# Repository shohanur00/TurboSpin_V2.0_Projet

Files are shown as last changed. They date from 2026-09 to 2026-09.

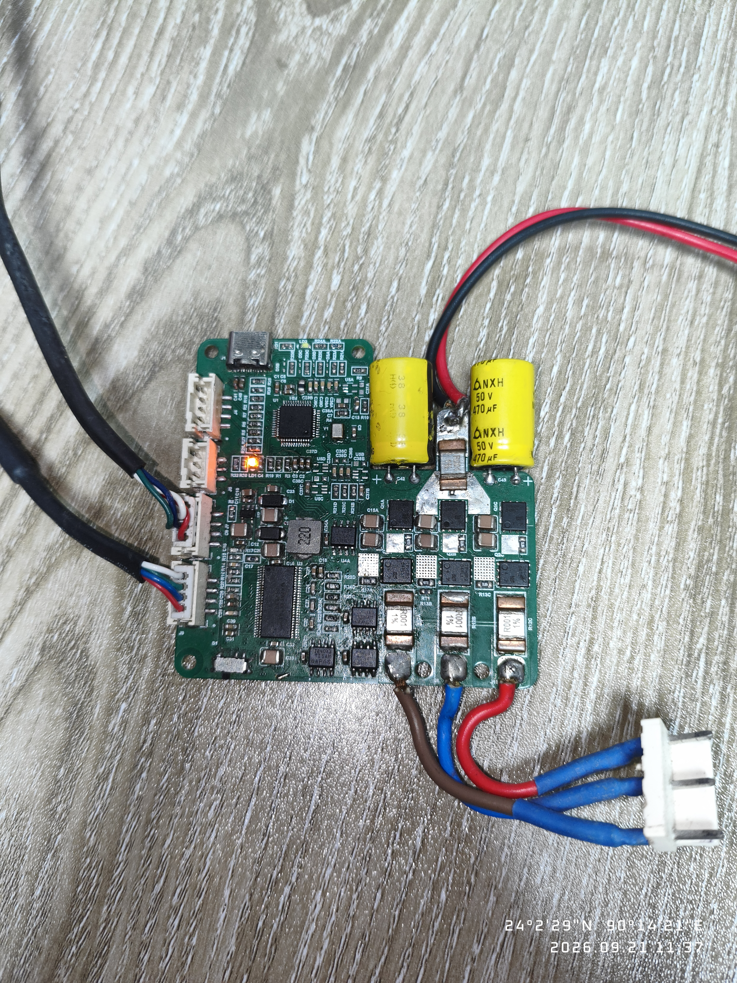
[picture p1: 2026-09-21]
Image/Hardware.jpeg

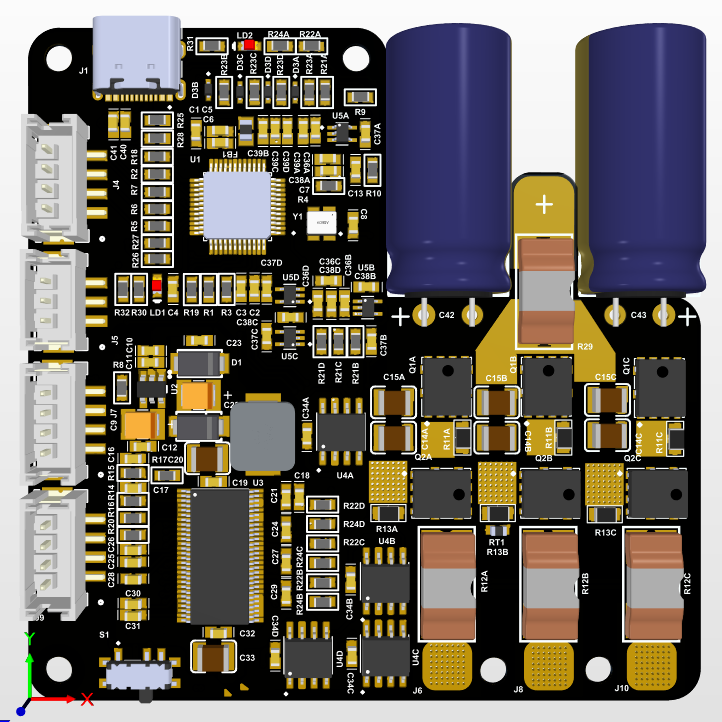
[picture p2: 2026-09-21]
Image/TurboSpin_V2_Front.png

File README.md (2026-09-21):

<div align="center">

# ⚡ TurboSpin V2

### 40A-class Sensorless BLDC / FOC ESC — Hardware Platform

*Design the hardware. Understand the current. Control the motor.*

<br>













</div>

---

**TurboSpin V2** is a custom **40A-class sensorless BLDC ESC** built around the **STM32G431CBT6** microcontroller and the **DRV8301** three-phase gate driver.

It is a compact, learning-oriented hardware platform with a dedicated power stage, current sensing and protection circuitry, and an MCU architecture ready for **six-step sensorless control and sensorless FOC** firmware.

> **Project status:** hardware design complete · firmware development in progress

## 📑 Contents

[Demo](#-demo) · [Key features](#-key-features) · [Architecture](#-hardware-architecture) · [Components](#-main-components) · [Subsystems](#-subsystems) · [Thermal](#-thermal-design) · [PCB philosophy](#-pcb-design-philosophy) · [Repository](#-repository-structure) · [Roadmap](#-roadmap) · [Safety](#-safety) · [Author](#-author)

---

## 🎬 Demo

<!-- Upload the clip to the repo (or drag it into a GitHub issue/README edit box) and update the path. -->
https://github.com/shohanur00/TurboSpin_V2.0_Projet/blob/main/Test/TurboSpin_V2.mp4

---

## ✨ Key Features

| | |
|---|---|
| ⚡ **Power** | 40A-class 3-phase MOSFET power stage |
| 🧠 **Control** | STM32G431CBT6 with advanced motor-control timers, fast ADCs and DMA |
| 🔌 **Gate drive** | DRV8301 with fault reporting |
| 📏 **Current sensing** | Low-side shunt + INA240A1 (20 V/V) |
| 🛡️ **Protection** | Hardware over-current architecture, gate-driver fault handling |
| 🔄 **Sensorless** | External comparator for back-EMF zero-cross detection |
| 📡 **Interfaces** | DShot and telemetry (planned), USB (planned), SWD debug |
| 🔥 **Layout** | High-current PCB with thermal considerations |

---

## 🏗️ Hardware Architecture

```text
                 ┌─────────────────────┐
                 │    Control Input    │
                 │  DShot / Future USB │
                 └──────────┬──────────┘
                            ▼
┌───────────────────────────────────────────────────────┐
│                     STM32G431CBT6                     │
│  PWM Generation │ ADC │ Timers │ DMA │ Protection     │
│               Future FOC / Control FW                 │
└─────────────┬─────────────────────────────▲───────────┘
              │ PWM (3 × complementary)     │ Current feedback
              ▼                             │
     ┌─────────────────┐            ┌───────┴──────────┐
     │     DRV8301     │            │ Shunt + INA240A1 │
     │  3-Phase Gate   │            └───────▲──────────┘
     │     Driver      │                    │
     └────────┬────────┘                    │
              ▼                             │
     ┌─────────────────┐                    │
     │  MOSFET Power   │────────────────────┘
     │  Stage (3 × ½B) │
     └────────┬────────┘
              │
        U ────┼──── V ──── W
              ▼
        BLDC / PMSM Motor
```

---

## 🔌 Main Components

| Function | Component |
| --- | --- |
| MCU | STM32G431CBT6 |
| Gate driver | DRV8301DCAR |
| Current amplifier | INA240A1 |
| Current shunt | 10 mΩ class <!-- TODO: verify final shunt value against BOM --> |
| Power MOSFET | TPH1R204PL1 |
| Motor phases | U / V / W |
| Control interface | DShot / future interfaces |
| Debug | SWD |
| USB | USB 2.0 |
| Sensorless feedback | External comparator |
| Input voltage | _TBD_ |

---

## 🧩 Subsystems

### 🧠 Microcontroller — STM32G431CBT6

Chosen for its motor-control peripherals: Cortex-M4 core, advanced PWM timers, high-speed ADCs, analog peripherals, DMA, multiple communication interfaces and SWD debugging.

```text
PWM Generation ──► 3-phase inverter
ADC ─────────────► Phase / bus current · DC bus voltage · Temperature
Comparator ──────► Sensorless feedback
                   └──► Motor control algorithm
```

### ⚡ Power Stage

A 3-phase MOSFET inverter with one high-side and one low-side switch per phase.

```text
                DC BUS
                  │
        ┌─────────┼─────────┐
       HS-U      HS-V      HS-W
        ├── U     ├── V     ├── W
       LS-U      LS-V      LS-W
        └─────────┼─────────┘
                 GND
```

Layout considerations: high-current paths, switching loops, gate-drive return paths, power/logic ground separation, current-sense routing, thermal dissipation, switching-node noise and low-inductance connections.

### 🔋 Gate Driver — DRV8301

Handles high-side / low-side gate drive, gate-drive supply management, current-sense amplifier interface, protection and fault reporting. The STM32 generates complementary PWM with firmware-controlled dead time to prevent shoot-through.

### 📏 Current Sensing

```text
Motor current ─► Low-side shunt ─► INA240A1 (20 V/V) ─► STM32 ADC
```

Used for current monitoring, limiting, protection, future FOC current-loop control and diagnostics. Kelvin-style routing around the shunt and amplifier keeps measurement error and switching noise low.

### 🛡️ Protection

Hardware and firmware layers, designed so critical faults can disable the power stage independently of normal control where practical:

* Over-current protection
* Gate-driver fault detection
* DC bus over-voltage / under-voltage monitoring
* MOSFET / board temperature monitoring
* PWM shutdown on fault

### 🔄 Sensorless Feedback

```text
Motor back-EMF ─► Comparator ─► STM32G431 ─► Zero-cross / rotor position
```

Supports six-step sensorless commutation, back-EMF zero-cross detection, sensorless startup and future sensorless FOC research.

### 🔌 USB and Communication

Planned: configuration, debugging, firmware update, parameter monitoring and PC tools over USB; DShot and telemetry for flight-controller use; SWD for debug. The USB pair is routed short with series termination. **Firmware support is not implemented yet**, and protocol details may evolve.

---

## 🌡️ Thermal Design

Key considerations: MOSFET dissipation, copper area around power devices, thermal vias, high-current routing, gate-driver thermals, shunt dissipation and PCB temperature monitoring.

> [!NOTE]
> **40A is a design-class target, not a guaranteed continuous rating.** Real capability depends on PCB construction, copper thickness, cooling, switching conditions, motor and environment.

---

## 🎯 PCB Design Philosophy

| Area | Approach |
| --- | --- |
| **Power path** | Short, wide, low-impedance, low-inductance |
| **Gate drive** | Compact loops to reduce ringing, EMI, switching loss and false triggering |
| **Current sense** | Sensitive traces routed away from switching nodes |
| **Grounding** | Power ground (high-current return, switching current) kept separate from signal/analog ground (ADC, current sense, control) to reduce ADC noise |

---

## 📂 Repository Structure

```text
TurboSpin_V2/
├── Hardware/
│   ├── Schematic/
│   ├── PCB/
│   ├── Gerber/
│   └── BOM/
├── Documentation/
│   ├── Hardware_Architecture.md
│   ├── Power_Stage.md
│   ├── Current_Sensing.md
│   └── Design_Notes.md
├── Firmware/
│   └── README.md
├── Images/
└── README.md
```

> Firmware directories may stay empty or hold development notes until firmware work begins.

---

## 🧪 Roadmap

**Hardware**

- [x] System architecture
- [x] Schematic design
- [x] Power-stage design
- [x] Current-sense design
- [x] MCU peripheral allocation
- [x] PCB design
- [ ] PCB fabrication
- [ ] Hardware bring-up
- [ ] Power-stage validation
- [ ] Current-sense calibration
- [ ] Protection testing

**Firmware**

- [ ] MCU startup
- [ ] PWM driver
- [ ] ADC driver
- [ ] Current measurement
- [ ] Gate-driver interface
- [ ] Fault handling
- [ ] Six-step BLDC control
- [ ] Sensorless zero-cross detection
- [ ] DShot
- [ ] Telemetry
- [ ] Closed-loop control
- [ ] Sensorless FOC
- [ ] USB configuration interface

---

## ⚠️ Safety

> [!WARNING]
> This project involves **high current, fast switching and potentially dangerous motors**. Improper testing can cause MOSFET failure, PCB or battery damage, fire, motor overspeed and flying mechanical parts.
>
> Test with current limiting, protective equipment and controlled conditions. Do not assume the 40A target is safe or achievable until the full thermal, electrical and mechanical system is validated.

---

## 👨‍💻 Author

**Md. Shohanur Rahman** — Embedded Systems / Hardware Design Engineer

Embedded systems · Motor control · BLDC / PMSM · Sensorless FOC · STM32 · Power electronics · PCB design · Hardware bring-up · Real-time firmware




---

<div align="center">

## ⭐ Why TurboSpin?

TurboSpin V2 isn't meant to be just another ESC board. It's a complete learning and engineering platform where **power electronics, PCB design, embedded firmware, motor control and real-time systems** come together.

**If you find this project useful, consider giving it a ⭐**

</div>

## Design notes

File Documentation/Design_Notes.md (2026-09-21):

# TurboSpin V2 — Design Notes

## Project Goal

TurboSpin V2 was developed as a personal learning and development platform for high-current BLDC motor control.

The project combines:

* Embedded systems
* Power electronics
* Motor control
* Analog signal measurement
* PCB design
* Real-time firmware development

The primary goal is to build and validate the hardware platform first and then develop the motor-control firmware incrementally.

## MCU Selection

### STM32G431CBT6

The STM32G431CBT6 was selected as the primary controller because it provides peripherals suitable for real-time motor-control applications.

Important requirements include:

* High-performance Cortex-M4 core
* Advanced timers
* Multiple ADC resources
* Fast interrupt response
* Flexible GPIO
* Communication peripherals
* Suitable development ecosystem

## Gate Driver Selection

### DRV8301

The DRV8301 was selected as the three-phase MOSFET gate-driver solution.

The device provides a dedicated interface between the MCU control signals and the external MOSFET bridge.

This reduces the need to implement the complete gate-drive stage using discrete circuitry.

## MOSFET Selection

### TPH1R204PL1

The selected MOSFET provides a combination of:

* 60 V voltage rating
* Low RDS(on)
* High current capability
* Compact power package

The low conduction resistance is particularly useful for reducing conduction losses in the three-phase inverter.

Actual operating current capability depends on PCB thermal performance, switching losses, cooling, bus voltage, motor characteristics, and operating conditions.

## Current Measurement

Low-value shunts and INA240 current-sense amplifiers were selected to provide a measurement path suitable for motor-control development.

The design intentionally keeps the shunt resistance low to reduce power dissipation while providing sufficient voltage for amplification.

## Switching Frequency

The target PWM frequency is:

```text
20 kHz
```

The frequency was selected as a practical starting point for BLDC motor-control development.

Actual switching losses and thermal performance must be validated experimentally.

## PCB Design Philosophy

The PCB was designed with particular attention to the difference between:

### Power Domain

High-current and high-frequency switching paths include:

* DC bus
* MOSFET bridge
* Motor phases
* Gate-drive loops
* Current shunts

### Signal Domain

Sensitive signals include:

* Current-sense outputs
* ADC inputs
* Control signals
* Communication interfaces
* Oscillator signals

The layout attempts to minimize unwanted coupling between these domains.

## Grounding

The design uses careful separation and routing of power-current paths and sensitive signal paths.

High-current return paths should not share narrow traces with sensitive analog measurement signals.

The final grounding performance must be verified experimentally using oscilloscope measurements and current-sense validation.

## USB

A USB Type-C connector is included on the board for development and interface purposes.

USB signal integrity depends on:

* Differential-pair routing
* Trace impedance
* Trace length matching
* Connector quality
* ESD protection
* Appropriate series termination

The final USB performance will be validated during hardware testing.

## Oscillator

An external 8 MHz CMOS oscillator is used as the clock source for the MCU.

The oscillator provides a stable external reference for the system clock configuration.

## Development Strategy

The project is being developed incrementally.

### Stage 1 — Hardware

* Schematic
* Component selection
* PCB layout
* Manufacturing
* Visual inspection

### Stage 2 — Hardware Bring-Up

* Power rails
* MCU programming
* Clock verification
* GPIO validation
* Gate-driver validation
* ADC validation
* Current-sense validation

### Stage 3 — Motor Control

Planned firmware development:

```text
PWM
 ↓
6-Step Commutation
 ↓
Open-Loop Startup
 ↓
Back-EMF / Zero-Cross Detection
 ↓
Sensorless BLDC Control
 ↓
DShot
 ↓
Telemetry
 ↓
FOC Research
```

## Current Project Status

The hardware design is the current focus of TurboSpin V2.

Firmware development has not yet been completed.

This repository will be updated as hardware bring-up, firmware development, testing, and motor-control experiments progress.

## Disclaimer

TurboSpin V2 is a personal engineering and learning project.

High-current motor controllers can involve hazardous voltages, currents, temperatures, and rotating machinery.

Testing should be performed with appropriate laboratory equipment, current limiting, protection, and safety procedures.

Do not assume the design is production-ready or that the stated component ratings represent the safe operating limit of the complete system.

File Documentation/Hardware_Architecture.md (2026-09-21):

# TurboSpin V2 — Hardware Architecture

## Overview

TurboSpin V2 is a custom high-current BLDC ESC hardware platform built around the STM32G431CBT6 microcontroller.

The hardware is designed as a foundation for developing sensorless BLDC motor control, digital throttle input, telemetry, and future FOC-based control.

The design is divided into several functional blocks:

```text
                    ┌──────────────────────┐
                    │      USB Type-C      │
                    │  Development / I/O   │
                    └──────────┬───────────┘
                               │
                               ▼
┌────────────────────────────────────────────────────┐
│                 STM32G431CBT6                      │
│                                                    │
│  PWM Generation   ADC   Timers   GPIO   Interfaces │
└───────┬──────────────┬───────────────┬─────────────┘
        │              │               │
        │              │               └── Control / I/O
        │              │
        │              └── Current / Voltage Feedback
        │
        ▼
┌──────────────────────┐
│      DRV8301         │
│   Gate Driver        │
└──────────┬───────────┘
           │
           ▼
┌────────────────────────────────┐
│       3-Phase Power Stage      │
│                                │
│   Phase A   Phase B   Phase C  │
│     │         │         │      │
│     └─────────┴─────────┘      │
└───────────────┬────────────────┘
                │
                ▼
             BLDC Motor
```

## Main Components

### Microcontroller

**STM32G431CBT6**

The STM32G431 is the main control device of TurboSpin V2.

Planned responsibilities include:

* PWM generation
* Motor commutation timing
* ADC sampling
* Current measurement
* Rotor position estimation
* Zero-crossing detection
* DShot input
* Telemetry
* Protection and fault handling

The MCU was selected because of its high-performance Cortex-M4 core and motor-control-oriented peripherals.

### Gate Driver

**DRV8301DCAR**

The DRV8301 is used to interface the STM32 control signals with the three-phase MOSFET power stage.

The gate-driver stage provides the required gate-drive capability for the external N-channel MOSFET bridge.

### Power Stage

The three-phase inverter consists of six N-channel power MOSFETs.

Each motor phase is controlled by a high-side and low-side MOSFET pair.

```text
             DC BUS
               │
        ┌──────┼──────┐
        │      │      │
       HS-A   HS-B   HS-C
        │      │      │
        A      B      C ────► BLDC Motor
        │      │      │
       LS-A   LS-B   LS-C
        │      │      │
        └──────┴──────┘
               │
              GND
```

### Current Sensing

TurboSpin V2 uses low-value shunt resistors together with INA240 current-sense amplifiers.

The current-sense signals are routed to the STM32 ADC subsystem for measurement and future closed-loop motor-control algorithms.

### Power Regulation

A dedicated 3.3 V LDO supplies the low-voltage digital and analog circuitry.

The power architecture separates the high-current motor path from sensitive control and measurement circuitry as much as practical.

## Development Direction

The hardware is intended to support the following development stages:

1. Hardware bring-up
2. PWM and gate-driver validation
3. Current-sense validation
4. 6-step BLDC commutation
5. Sensorless operation
6. DShot interface
7. ESC telemetry
8. Future FOC development

> Firmware implementation is currently under development.

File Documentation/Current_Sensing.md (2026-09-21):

# TurboSpin V2 — Current Sensing

## Overview

Accurate current measurement is an important part of a BLDC ESC.

TurboSpin V2 uses low-value shunt resistors together with INA240 current-sense amplifiers to measure motor current.

The measured signals are intended to be sampled by the STM32G431 ADC.

## Shunt Resistors

The design uses:

```text
Shunt Resistance = 1 mΩ
```

Low-value shunt resistors are used to minimize power loss while still producing a measurable voltage proportional to current.

The basic relationship is:

```text
VSHUNT = IMOTOR × RSHUNT
```

For a 1 mΩ shunt:

```text
VSHUNT = IMOTOR × 0.001
```

For example:

```text
I = 20 A

VSHUNT = 20 × 0.001
       = 20 mV
```

## Current Sense Amplifier

**INA240A1D**

The INA240 is used to amplify the small voltage developed across the shunt resistor.

The selected A1 variant provides:

```text
Gain = 20 V/V
```

Therefore:

```text
VOUT ≈ VSHUNT × 20
```

For example:

```text
20 mV × 20 = 400 mV
```

This amplified signal can then be measured by the STM32 ADC.

## Signal Chain

```text
Motor Current
     │
     ▼
┌──────────────┐
│  1 mΩ Shunt  │
└──────┬───────┘
       │
       ▼
┌──────────────┐
│   INA240A1   │
│    Gain 20   │
└──────┬───────┘
       │
       ▼
┌──────────────┐
│ STM32G431    │
│     ADC      │
└──────────────┘
```

## PWM Rejection

The INA240 is specifically useful in motor-control applications because of its enhanced PWM rejection capability.

This is important because the current-sense circuitry operates in an environment containing:

* High dV/dt switching
* High di/dt current transitions
* PWM switching edges
* MOSFET gate-drive activity

## ADC Interface

The amplified current-sense outputs are connected to STM32 ADC inputs.

Firmware will eventually use these measurements for:

* Current monitoring
* Over-current protection
* Motor-control algorithms
* Current limiting
* Future FOC implementation

## Layout Considerations

Current sensing is highly sensitive to PCB layout.

The following principles are used:

* Kelvin-style sensing where applicable
* Short shunt-sense connections
* Minimized high-current coupling into sense traces
* Separation from switching nodes
* Careful analog ground routing
* Short connection between shunt and amplifier

## Calibration

Before using current measurements for closed-loop control, the system should be calibrated for:

* ADC offset
* Amplifier offset
* Shunt tolerance
* Gain error
* ADC reference accuracy

A practical calibration flow can be:

```text
Power ON
   │
   ▼
Measure zero-current ADC value
   │
   ▼
Calculate offset
   │
   ▼
Apply offset correction
   │
   ▼
Convert ADC value → Current
```

The final conversion equation will be implemented in firmware after hardware validation.

> Current-sense accuracy should be verified experimentally using a calibrated external measurement method before using the signal for protection or closed-loop control.

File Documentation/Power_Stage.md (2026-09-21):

# TurboSpin V2 — Power Stage

## Overview

The TurboSpin V2 power stage is a three-phase inverter designed to drive a high-current BLDC motor.

The inverter consists of six N-channel power MOSFETs arranged as three half-bridges.

## Three-Phase Inverter

Each motor phase contains:

* One high-side MOSFET
* One low-side MOSFET
* Gate-drive connection
* Current path through the power stage

```text
                DC+
                 │
        ┌────────┼────────┐
        │        │        │
      Q1A      Q1B      Q1C
        │        │        │
        A        B        C
        │        │        │
      Q2A      Q2B      Q2C
        │        │        │
        └────────┼────────┘
                 │
                GND
```

The three switching nodes are connected to the corresponding BLDC motor phases.

## MOSFET

**TPH1R204PL1**

Key characteristics used in the design include:

* N-channel MOSFET
* 60 V drain-source rating
* Approximately 3 mΩ typical RDS(on)
* High-current capability
* PowerFLAT 5×6 package

Six MOSFETs are used in the complete three-phase bridge.

## Gate Driver

The MOSFET gates are controlled through the **DRV8301** gate-driver IC.

The MCU generates the control signals while the gate driver provides the required interface between the MCU and power MOSFETs.

The gate-driver section is also responsible for maintaining appropriate switching behavior and dead-time between complementary high-side and low-side devices.

## PWM

The target PWM frequency for TurboSpin V2 is:

```text
PWM Frequency = 20 kHz
```

A high-frequency PWM scheme is used to provide suitable motor-control resolution while keeping switching operation above the typical audible range.

## Dead-Time

Dead-time is required between turning off one MOSFET and turning on its complementary MOSFET.

Conceptually:

```text
High Side:  ────────┐       ┌────────
                    │       │
                    └───────┘

Low Side:   ───────────────┐       ┌──
                           │       │
                           └───────┘

                 ← Dead Time →
```

The exact dead-time value is configured according to the selected MOSFET, gate-driver behavior, switching characteristics, and measured hardware performance.

## Current Path

High-current PCB routing is kept as short and low-impedance as practical.

Special attention is given to:

* MOSFET-to-MOSFET current loops
* DC bus connections
* Motor phase routing
* Shunt resistor connections
* Gate-drive loops
* Power and signal ground arrangement

## PCB Considerations

The power-stage layout is designed with the following objectives:

* Minimize high-current loop area
* Reduce parasitic inductance
* Keep gate-drive paths short
* Separate sensitive analog signals from high-current switching nodes
* Provide adequate copper for high-current paths
* Maintain controlled thermal paths around power devices

## Protection Considerations

The hardware includes provisions for monitoring and controlling the motor power stage.

Protection strategy may include:

* Over-current detection
* DC bus over-voltage monitoring
* Under-voltage monitoring
* MOSFET/gate-driver fault handling
* Firmware-based shutdown

The final protection behavior will depend on the firmware implementation and hardware validation.

> Power-stage limits must be experimentally validated before high-current operation.

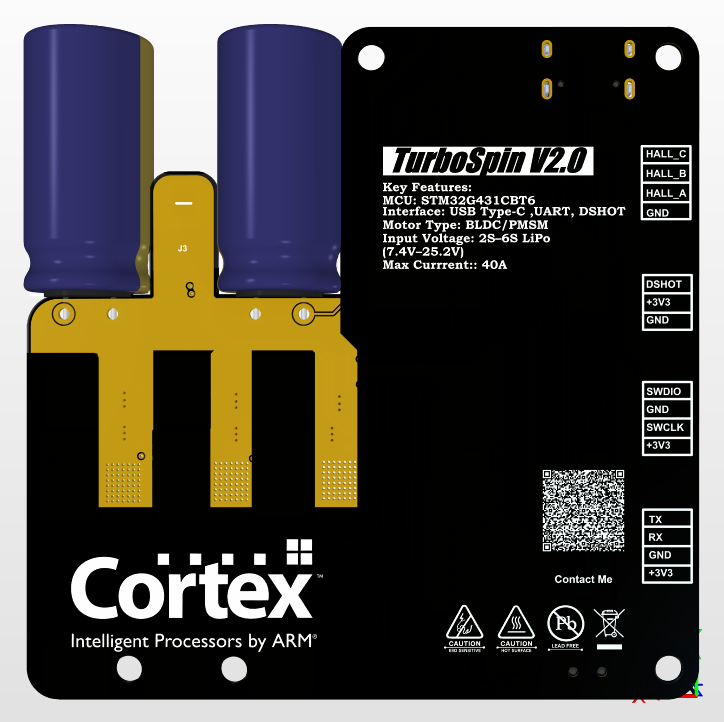
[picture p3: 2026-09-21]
Image/TurboSpin_V2_Back.png

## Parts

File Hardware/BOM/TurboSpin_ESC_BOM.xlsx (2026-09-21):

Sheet: BOM
TurboSpin ESC — Bill of Materials
Ref. Des. | Value / Part No. | Rating / Specification | Package / Size | Tolerance | Qty | Category
C1,C2,C3,C4,C6,C7,C13,C41 | 100nF | 16V | 0603 | 20% | 8 | Capacitor
C5,C23,C25,C26,C34A,C34B,C34C,C34D,C37A,C37B,C37C,C37D | 2.2uF | 16V | 0603 | 20% | 12 | Capacitor
C8 | 10nF | 16V | 0603 | 20% | 1 | Capacitor
C9,C22 | 100uF | 6.3V | 3528 | 10% | 2 | Capacitor
C10,C11,C12 | 100nF | 16V | 0603 | 20% | 3 | Capacitor
C14A,C14B,C14C,C15A,C15B,C15C,C20,C33 | 4.7uF | 100V | 1210 | 20% | 8 | Capacitor
C16 | 120pF | 50V | 0603 | 20% | 1 | Capacitor
C17 | 6.8nF | 50V | 0603 | 20% | 1 | Capacitor
C18 | 15nF | 50V | 0603 | 20% | 1 | Capacitor
C19,C32 | 100nF | 100V | 0603 | 20% | 2 | Capacitor
C21,C24,C27,C29 | 100nF | 50V | 0603 | 20% | 4 | Capacitor
C28 | 22nF | 16V | 0603 | 20% | 1 | Capacitor
C30,C31 | 1uF | 16V | 0603 | 20% | 2 | Capacitor
C36A,C36B,C36C,C36D,C39A,C39B,C39C,C39D | 1nF | 16V | 0603 | 20% | 8 | Capacitor
C38A,C38B,C38C,C38D | 15nF | 16V | 0603 | 20% | 4 | Capacitor
C40 | 10uF | 16V | 0603 | 20% | 1 | Capacitor
C42,C43 | 1000uF | 100V |  | 20% | 2 | Capacitor
D1 | SMAJ5.0A_C35344 |  |  |  | 1 | TVS Diode
D2 | SS36 |  |  |  | 1 | Schottky Diode
D3A,D3B,D3C,D3D | BAT54K |  |  |  | 4 | Schottky Diode
FB1 | MPZ2012S601ATD | 600 Ohms @ 100MHz | 0805 |  | 1 | Ferrite Bead, 2A, 100mΩ
J1 | TYPE-C-31-M-12 |  |  |  | 1 | USB Type-C Receptacle, 24P, 8.94×7.3mm, RoHS
J2,J3,J6,J8,J10 | B1B Connector Header |  | THT, 5-position, 2.50mm |  | 5 | Connector
J4,J7,J9 | B5BXH-A Connector Header |  | THT, 5-position, 2.50mm |  | 3 | Connector
J5 | B4BXH-A Connector Header |  | THT, 5-position, 2.50mm |  | 1 | Connector
L1 | 22uH |  | 7×6.6mm |  | 1 | Inductor
LD1,LD2 | 1.8Vf, 25mA, 5mW |  |  |  | 2 | LED
Q1A,Q1B,Q1C,Q2A,Q2B,Q2C | TPH1R204PL1 | 60V, 3mΩ typ., 130A | PowerFLAT 5×6 |  | 6 | N-Channel Power MOSFET
R1,R4,R5,R6,R7,R8,R9,R16,R18,R19,R24A,R24B,R24C,R24D | 10K |  | 0603 | 1% | 14 | Resistor
R2,R3,R10,R23A,R23B,R23C,R23D | 100R |  | 0603 | 1% | 7 | Resistor
R11A,R11B,R11C,R13A,R13B,R13C | 4.7R |  | 0805 | 1% | 6 | Resistor
R12A,R12B,R12C,R29 | 0.001R |  | 3920 | 1% | 4 | Shunt Resistor
R14 | 52.3K |  | 0603 | 1% | 1 | Resistor
R15 | 16.2K |  | 0603 | 1% | 1 | Resistor
R17 | 200K |  | 0603 | 1% | 1 | Resistor
R20 | 1R |  | 0603 | 1% | 1 | Resistor
R21A,R21B,R21C,R21D,R30,R31 | 1K |  | 0603 | 1% | 6 | Resistor
R22A,R22B,R22C,R22D | 120K |  | 0603 | 1% | 4 | Resistor
R25,R28 | 5.1K |  | 0603 | 1% | 2 | Resistor
R26,R27 | 22R |  | 0603 | 1% | 2 | Resistor
R32 | 47R |  | 0603 | 1% | 1 | Resistor
RT1 | NCP18XH103F03RB | 10K | 0603 (1608 Metric) |  | 1 | NTC Thermistor
S1 | SW_SSSS811101 | 0.3A, 5VDC, 10000 cycles | SPST, Side Slide, Gull Wing SMD |  | 1 | Slide Switch
U1 | STM32G431CBT6 |  |  |  | 1 | MCU
U2 | RY6212 3V3 | 3V3 LDO, low noise | SOT23-5 |  | 1 | LDO Regulator
U3 | DRV8301DCAR |  | 56-HTSSOP |  | 1 | 3-Phase Gate Driver
U4A,U4B,U4C,U4D | INA240A1D | -4 to 80V, bidirectional |  |  | 4 | Current Sense Amplifier, 20V/V
U5A,U5B,U5C,U5D | SN74LVC1G66DCKR | 5V, 1:1 SPST analog switch |  |  | 4 | Analog Switch
Y1 | TFOM8M4RHKCN T2T | 8MHz, 3.3V, Enable/Disable, CMOS | 4-SMD, No Lead |  | 1 | Oscillator

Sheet: Summary
Category | Line Items | Total Qty
Capacitor | 16 | 58
Capacitor (value incomplete in source) | 1 | 3
TVS Diode | 1 | 1
Schottky Diode | 2 | 5
Ferrite Bead, 2A, 100mΩ | 1 | 1
USB Type-C Receptacle, 24P, 8.94×7.3mm, RoHS | 1 | 1
Connector | 3 | 9
Inductor | 1 | 1
LED | 1 | 2
N-Channel Power MOSFET | 1 | 6
Resistor | 12 | 46
Shunt Resistor | 1 | 4
NTC Thermistor | 1 | 1
Slide Switch | 1 | 1
MCU | 1 | 1
LDO Regulator | 1 | 1
3-Phase Gate Driver | 1 | 1
Current Sense Amplifier, 20V/V | 1 | 4
Analog Switch | 1 | 4
Oscillator | 1 | 1

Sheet: Notes
BOM Notes
1. | C10, C11, C12 capacitor value is incomplete in the supplied text ('uF VAC %'). Verify from the schematic before purchasing.
2. | C14A–C15C, etc. were kept exactly as supplied; verify the intended capacitor value/package against the schematic.
3. | Several source lines contain conflicting package/tolerance text. The BOM uses the explicit value/package/tolerance where clear and preserves the provided data.
4. | Connector part-number descriptions should be verified against the manufacturer's exact ordering code before procurement.

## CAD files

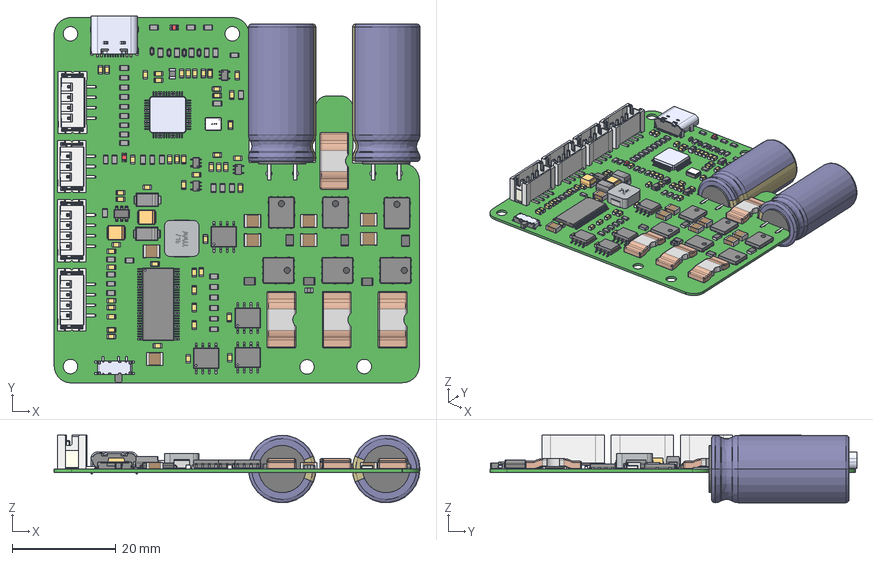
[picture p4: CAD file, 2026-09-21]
Hardware/3D/TurboSpin.step
70.4 x 70.6 x 13.0 mm
Mid Body x 40
Mark x 46
User Library-DO-214AC SMA x 2
Body001 (Mirror #1) x 16
XY-plane x 48
X-axis x 48
Leader x 6
NCP18XH103F03RB
User Library-LRMAP3920 x 4
Mid_Body x 6
User_Library-LTST-C190GKT_Pad005 x 2
User_Library-LTST-C190GKT_Pad001 x 2
User_Library-LTST-C190GKT_Pad006 x 2
User_Library-LTST-C190GKT_Pad004 x 2
User_Library-LTST-C190GKT_Pad003 x 2
User_Library-LTST-C190GKT_Pad007 x 2
User_Library-LTST-C190GKT_Lens x 2
User_Library-LTST-C190GKT_Pad x 2
String+ x 2
String- x 2
HA72L-0630
User Library-DS1066-04-4MSV6 x 3
User Library-DS1066-04-3MSV6
TYPE-C-31-M-12
rubber_pad x 2
can x 2
shell_and_minus x 2
shell_and_minus_2 x 2
lead x 4
User Library-cap_1210_lowprofile x 8

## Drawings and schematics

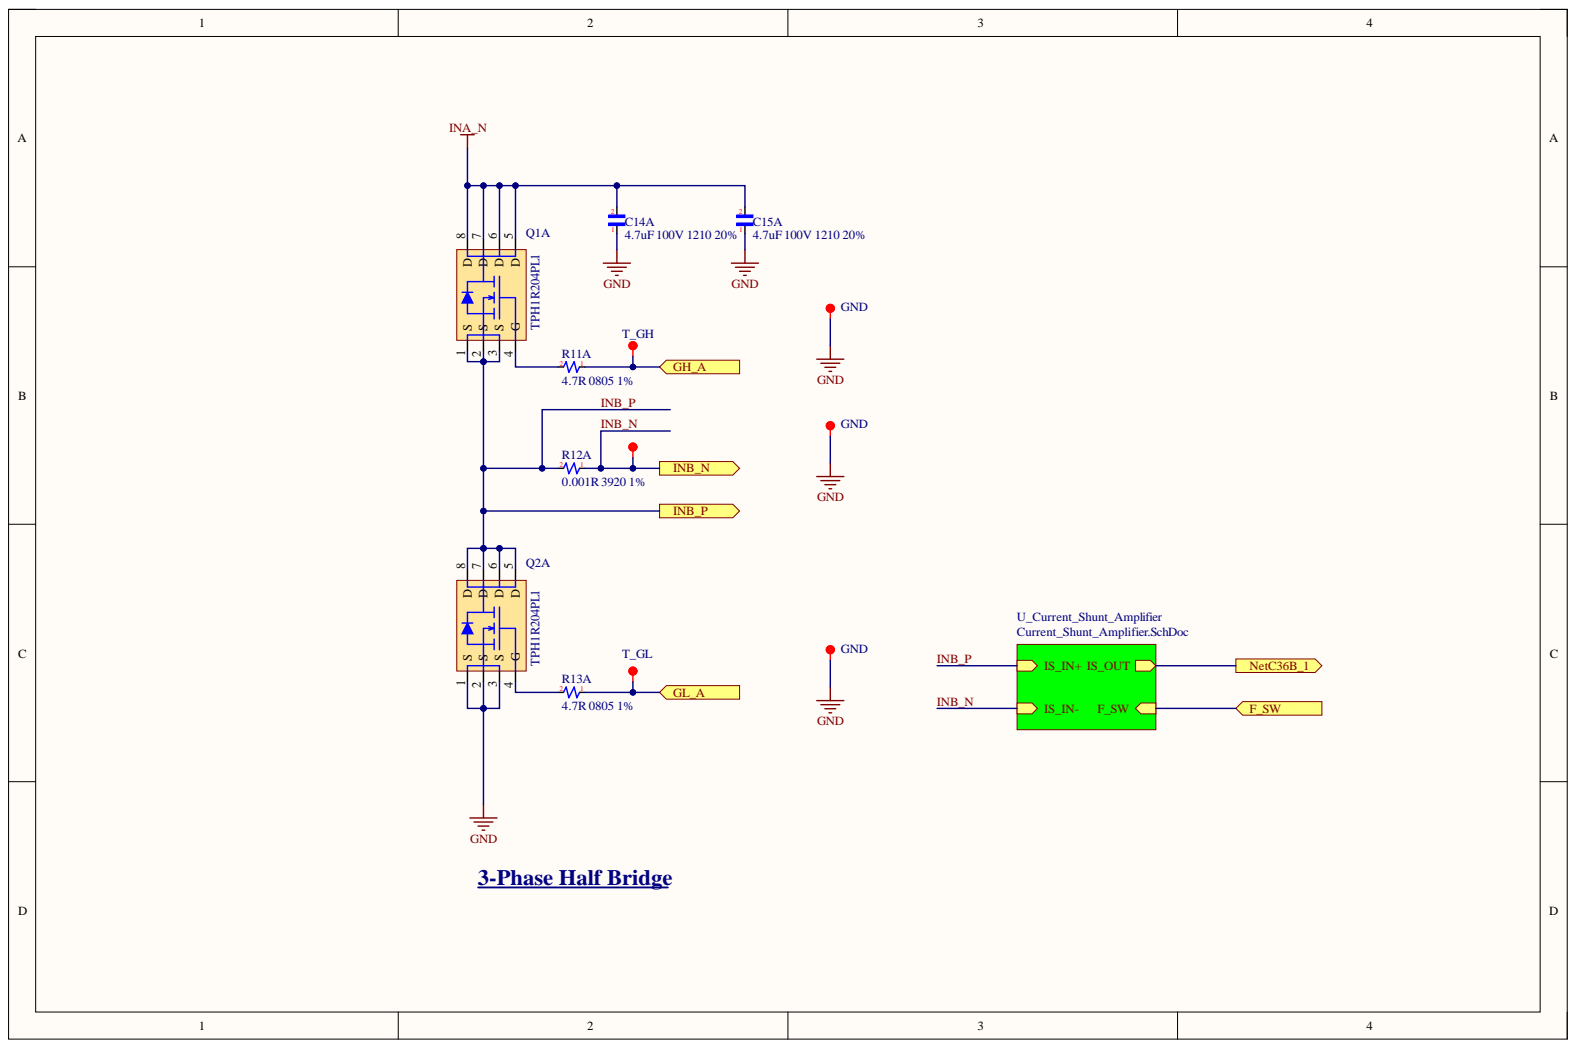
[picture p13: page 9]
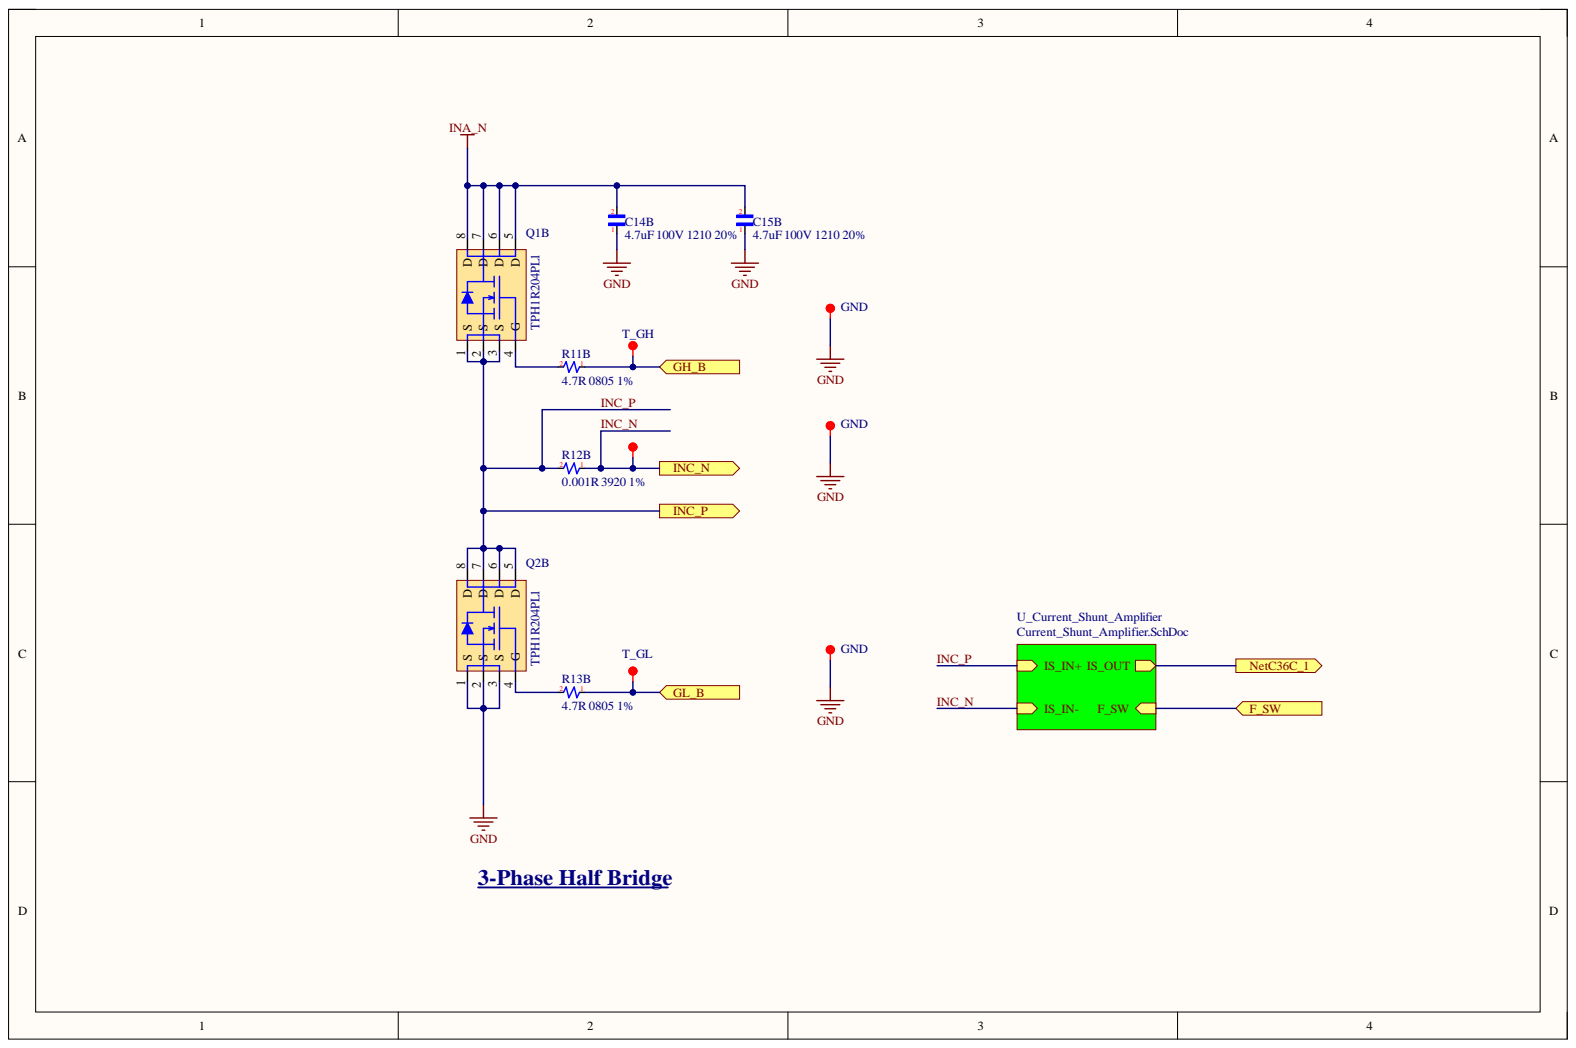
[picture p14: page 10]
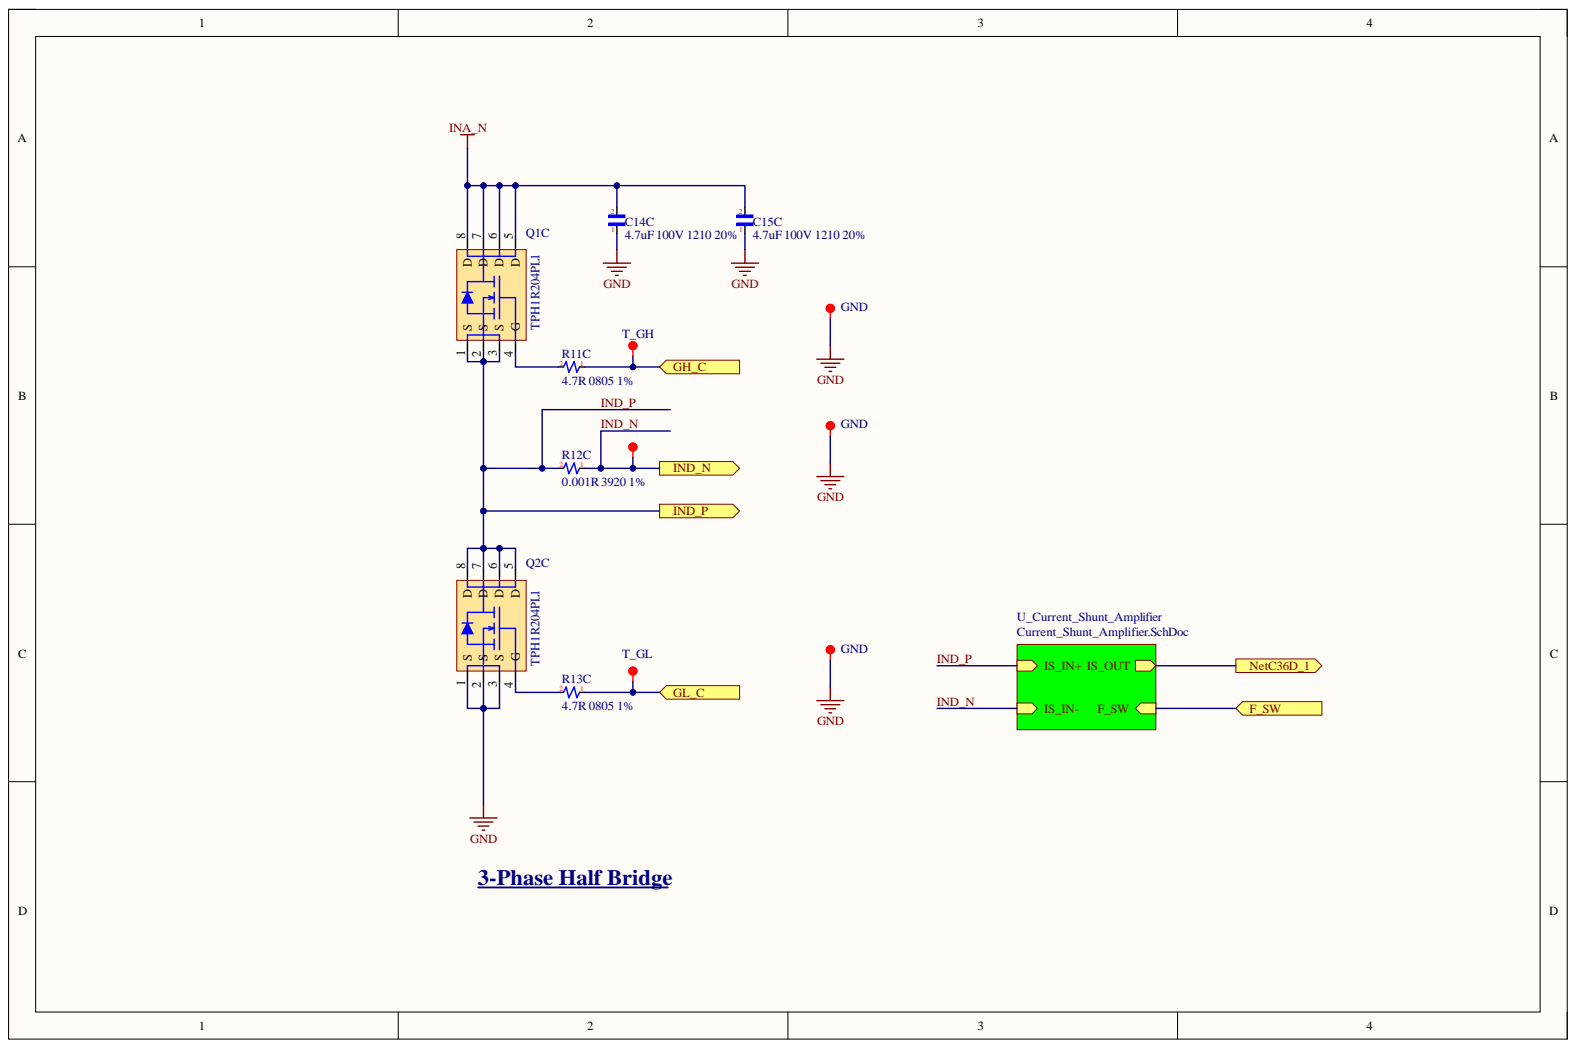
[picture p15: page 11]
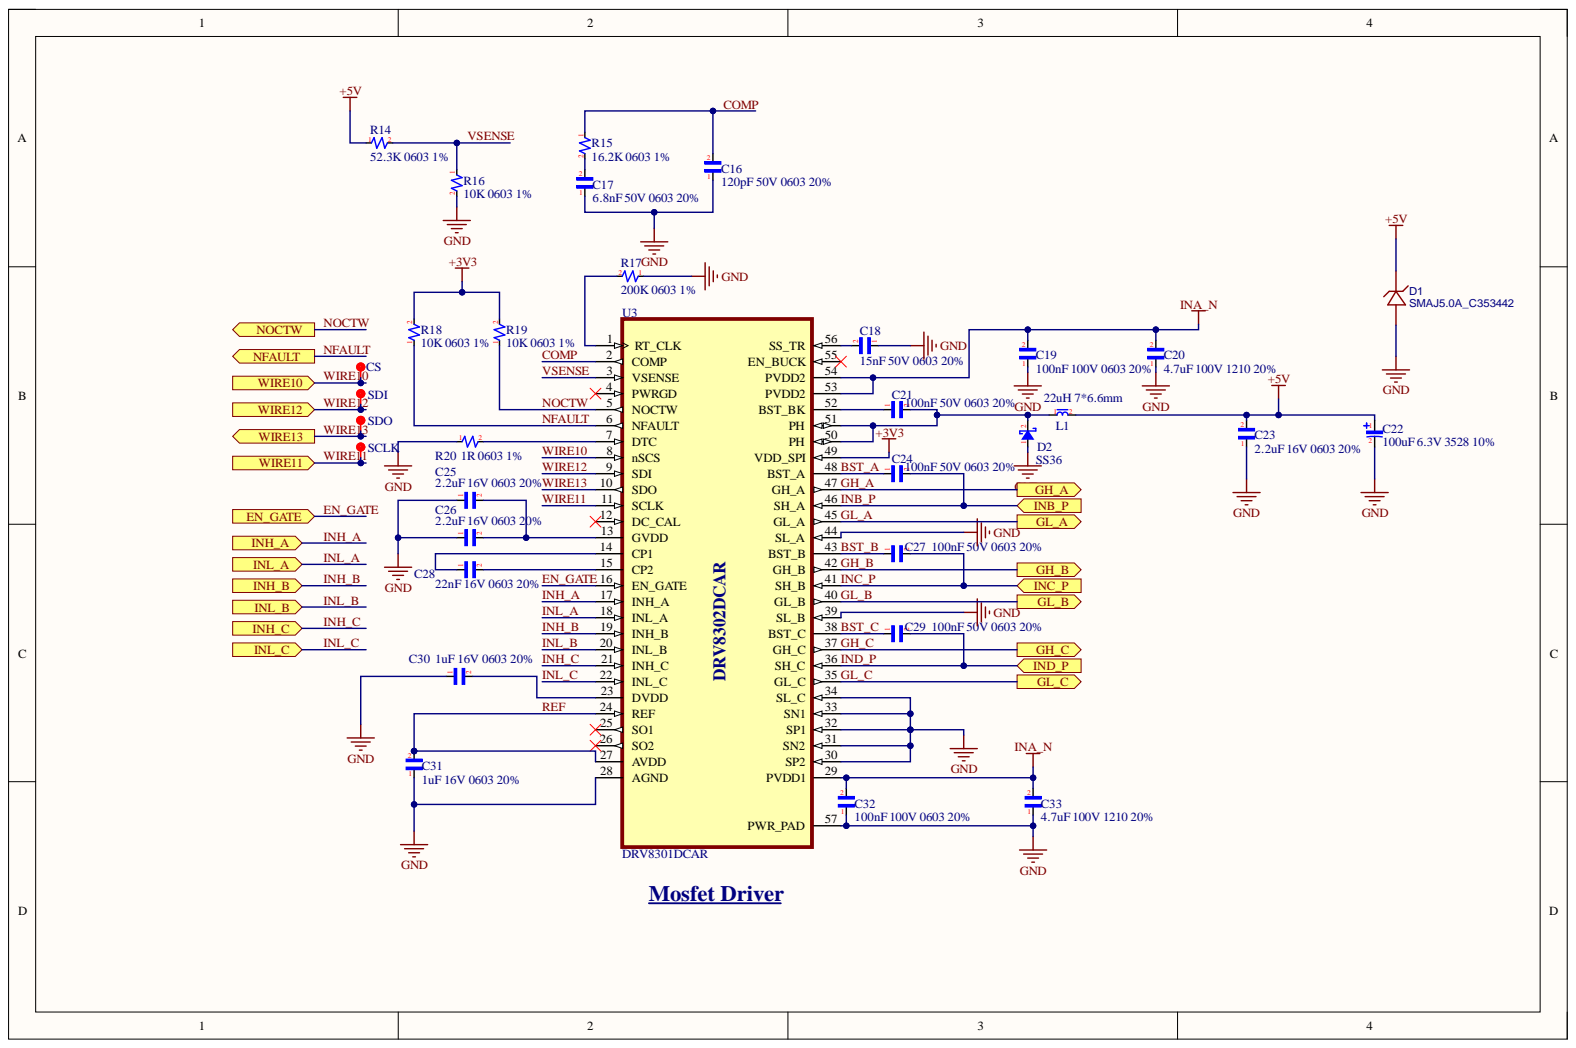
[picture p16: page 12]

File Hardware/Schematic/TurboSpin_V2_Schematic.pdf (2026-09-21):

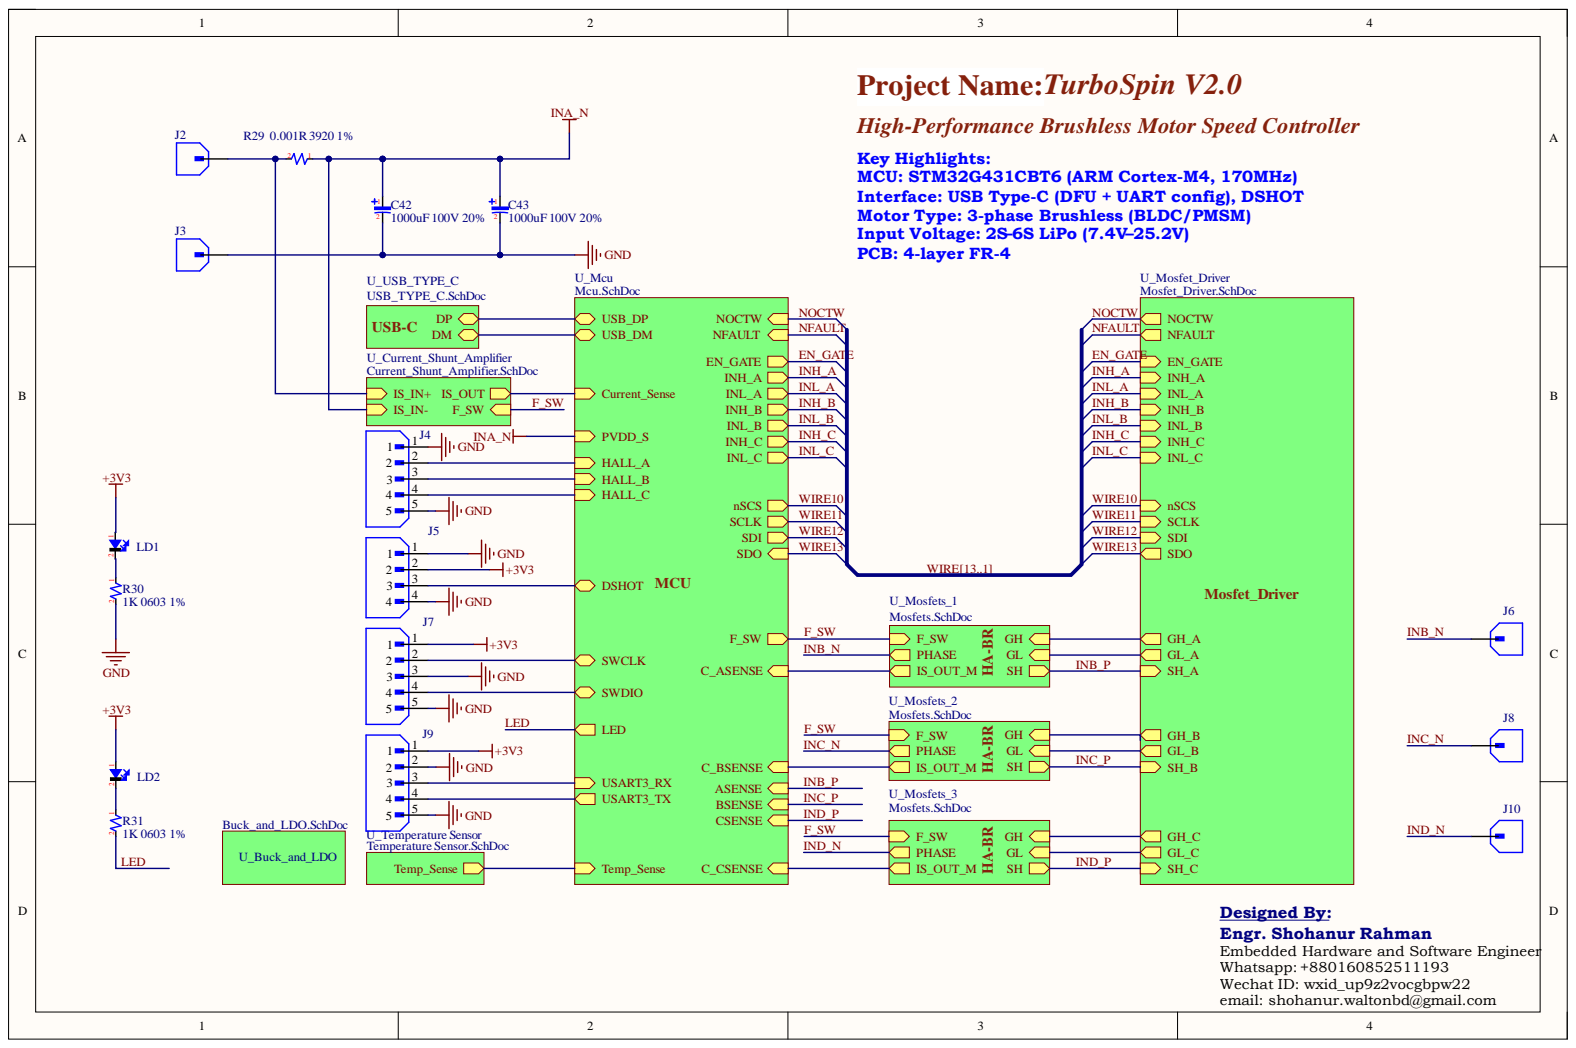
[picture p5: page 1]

High-Performance Brushless Motor Speed Controller

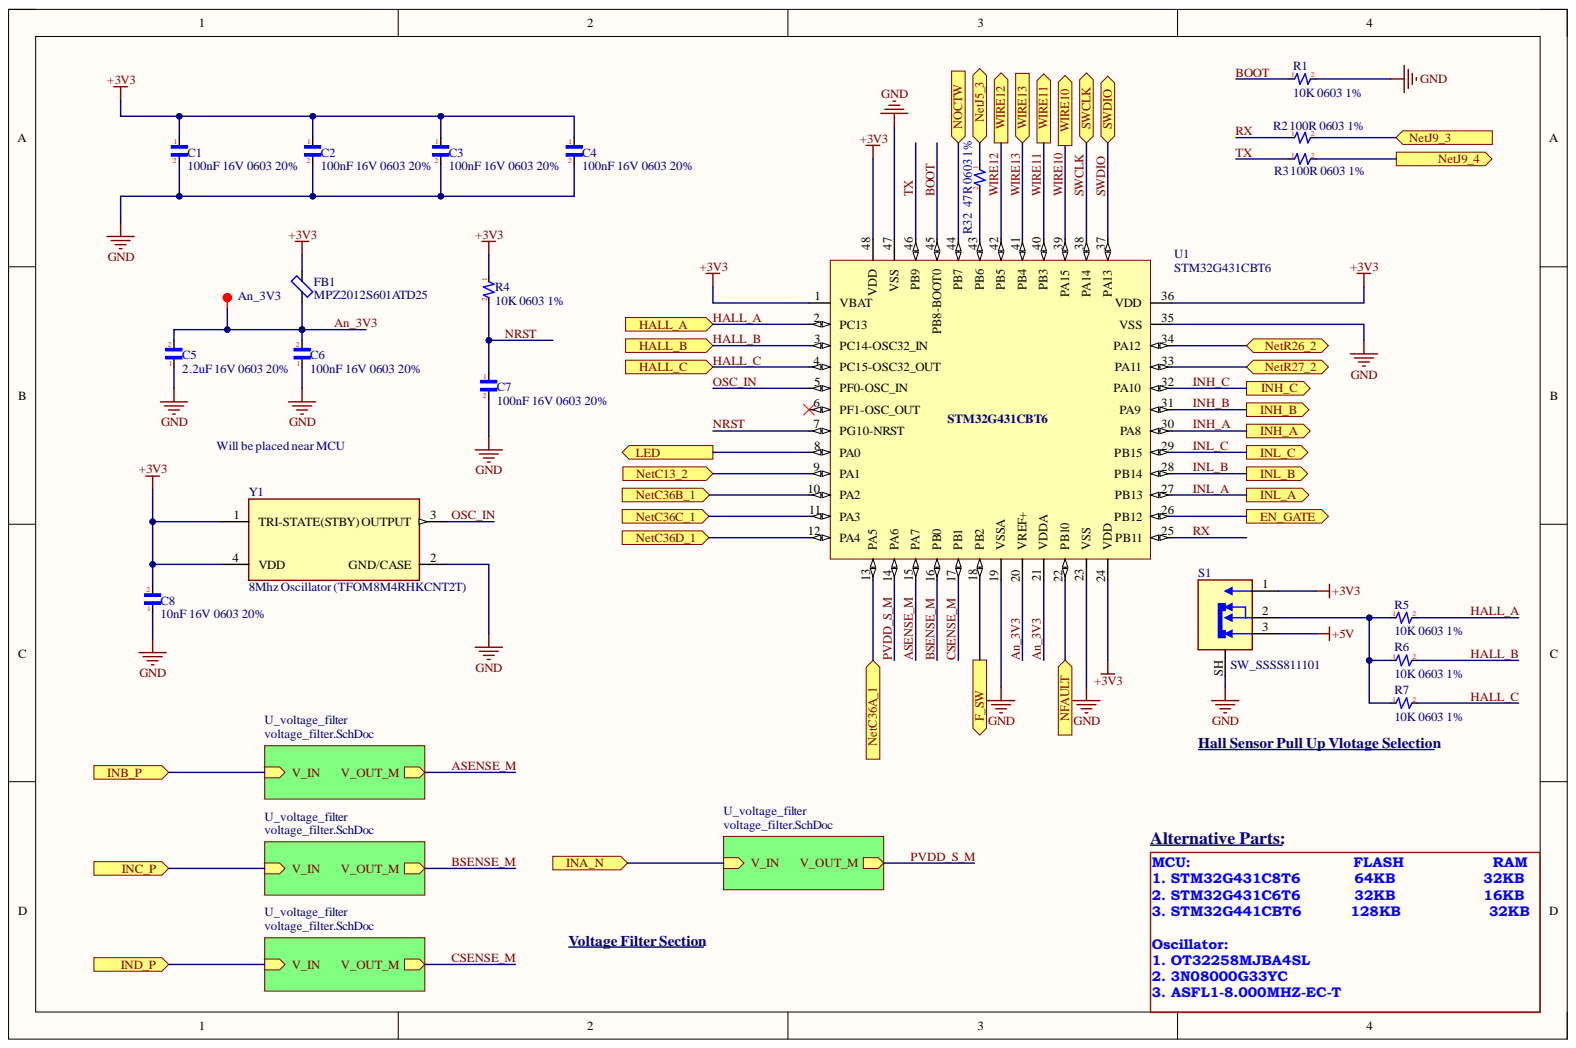
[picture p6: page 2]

Will be placed near MCU

GND
Hall Sensor Pull Up Vlotage Selection

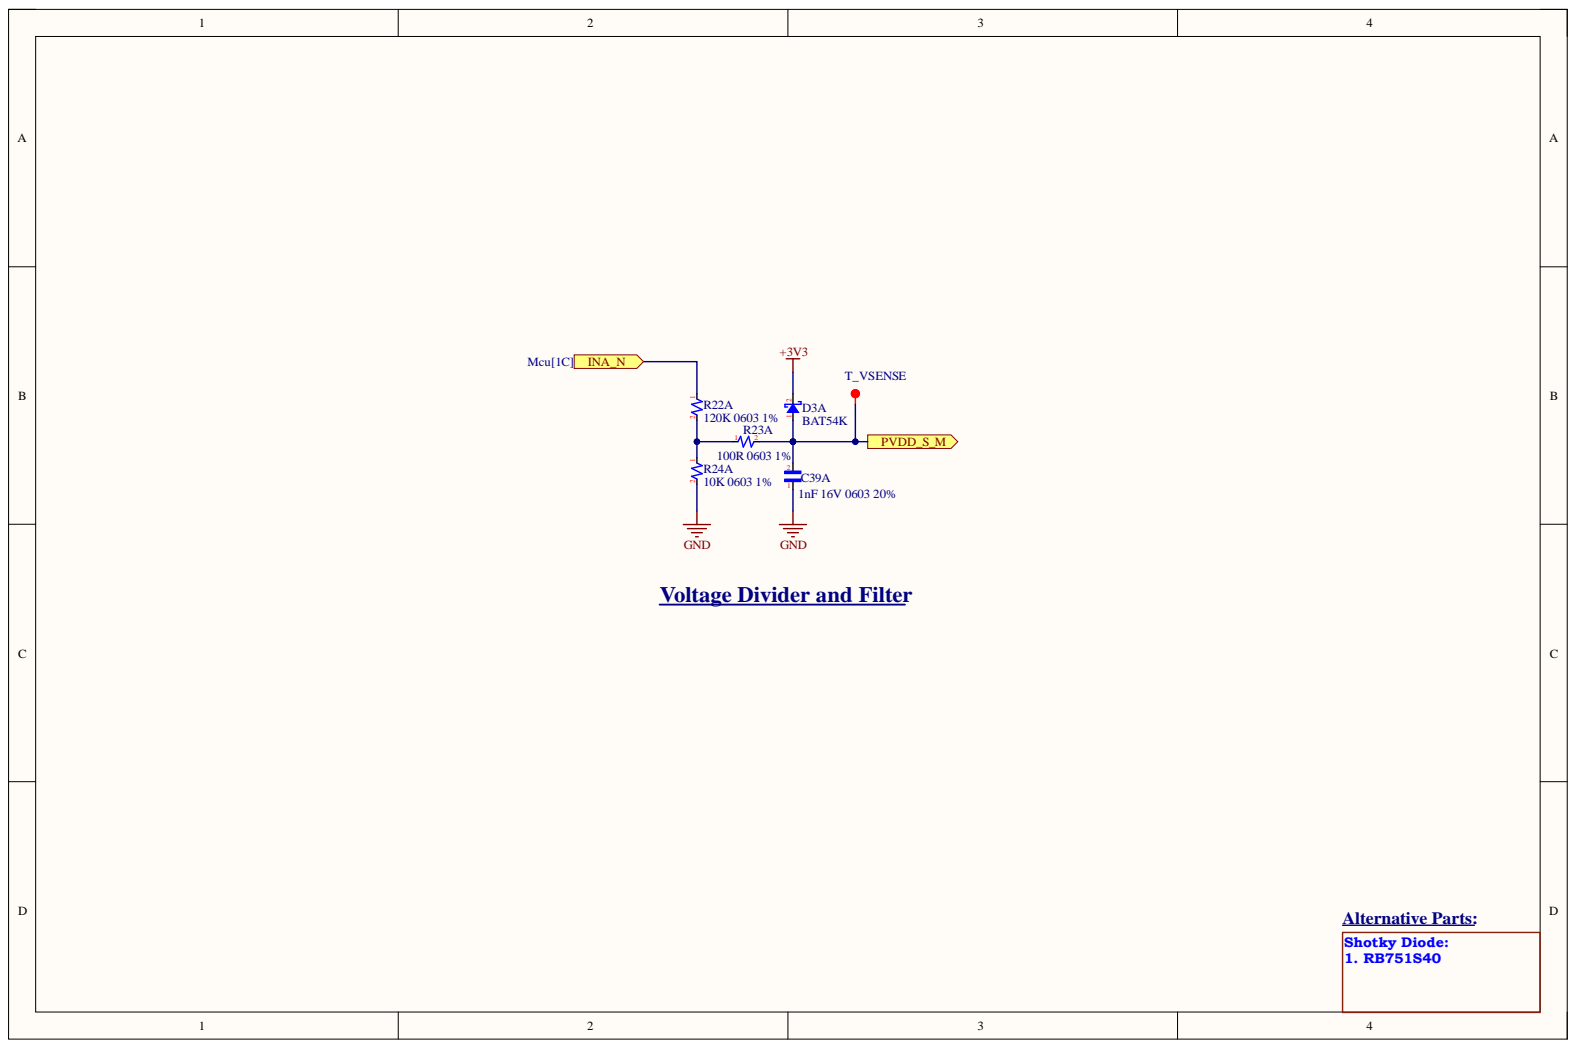
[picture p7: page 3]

Voltage Divider and Filter

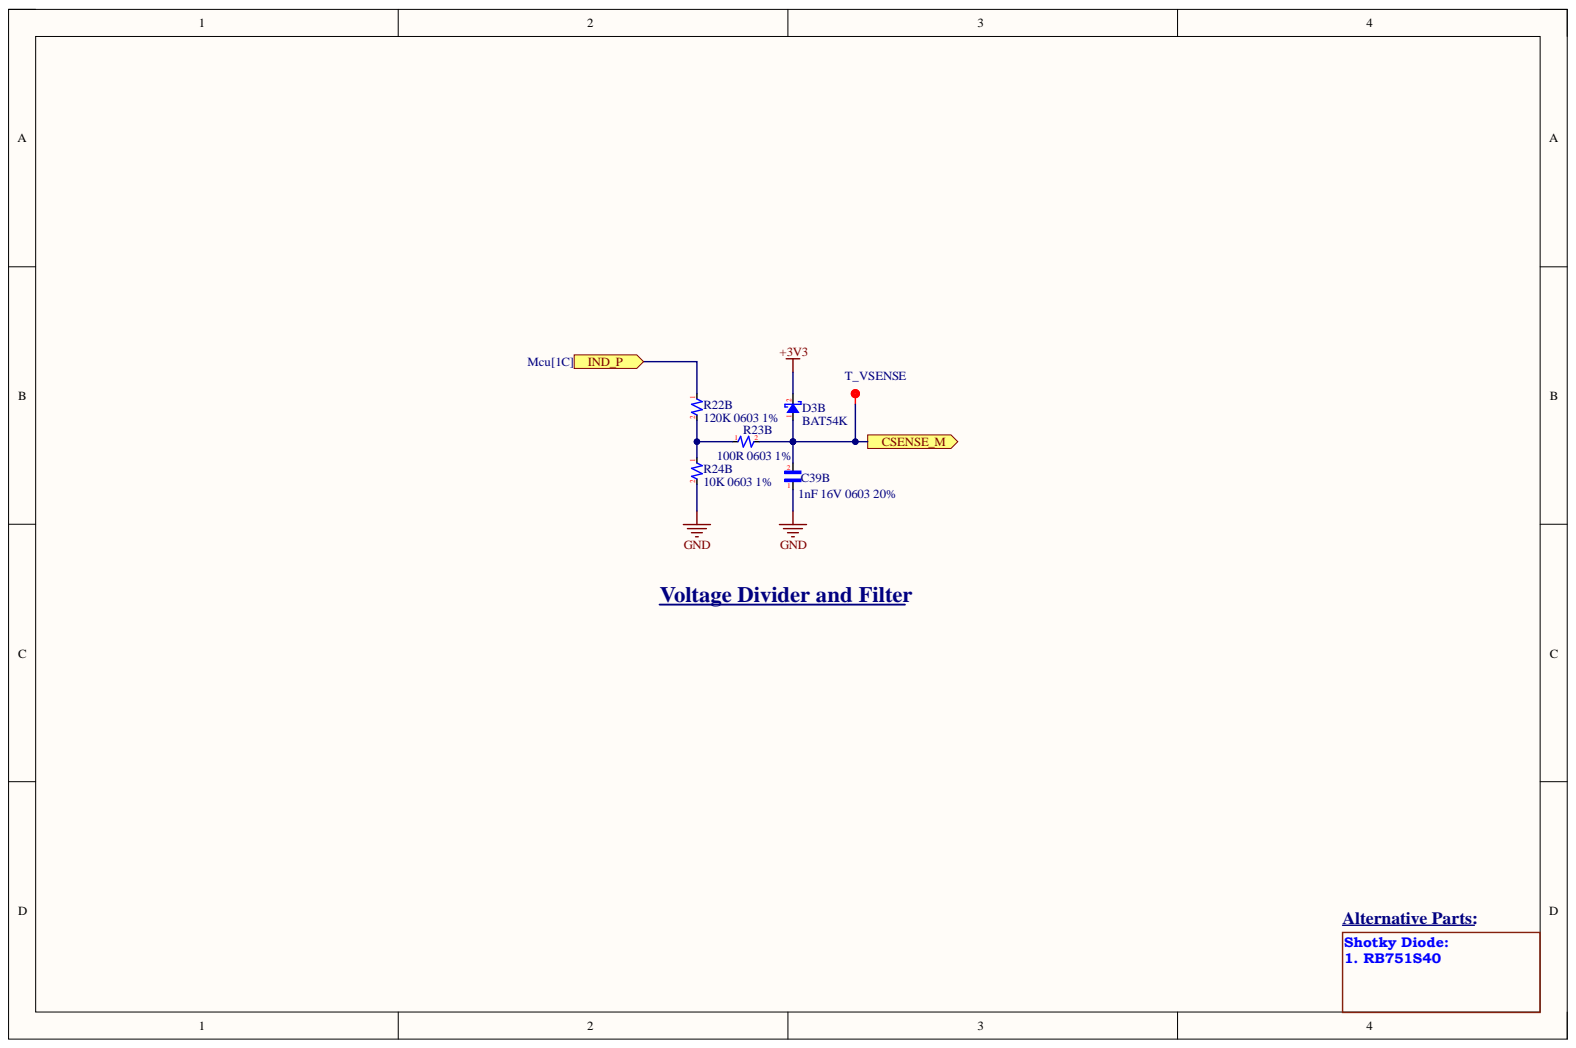
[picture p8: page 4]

Voltage Divider and Filter

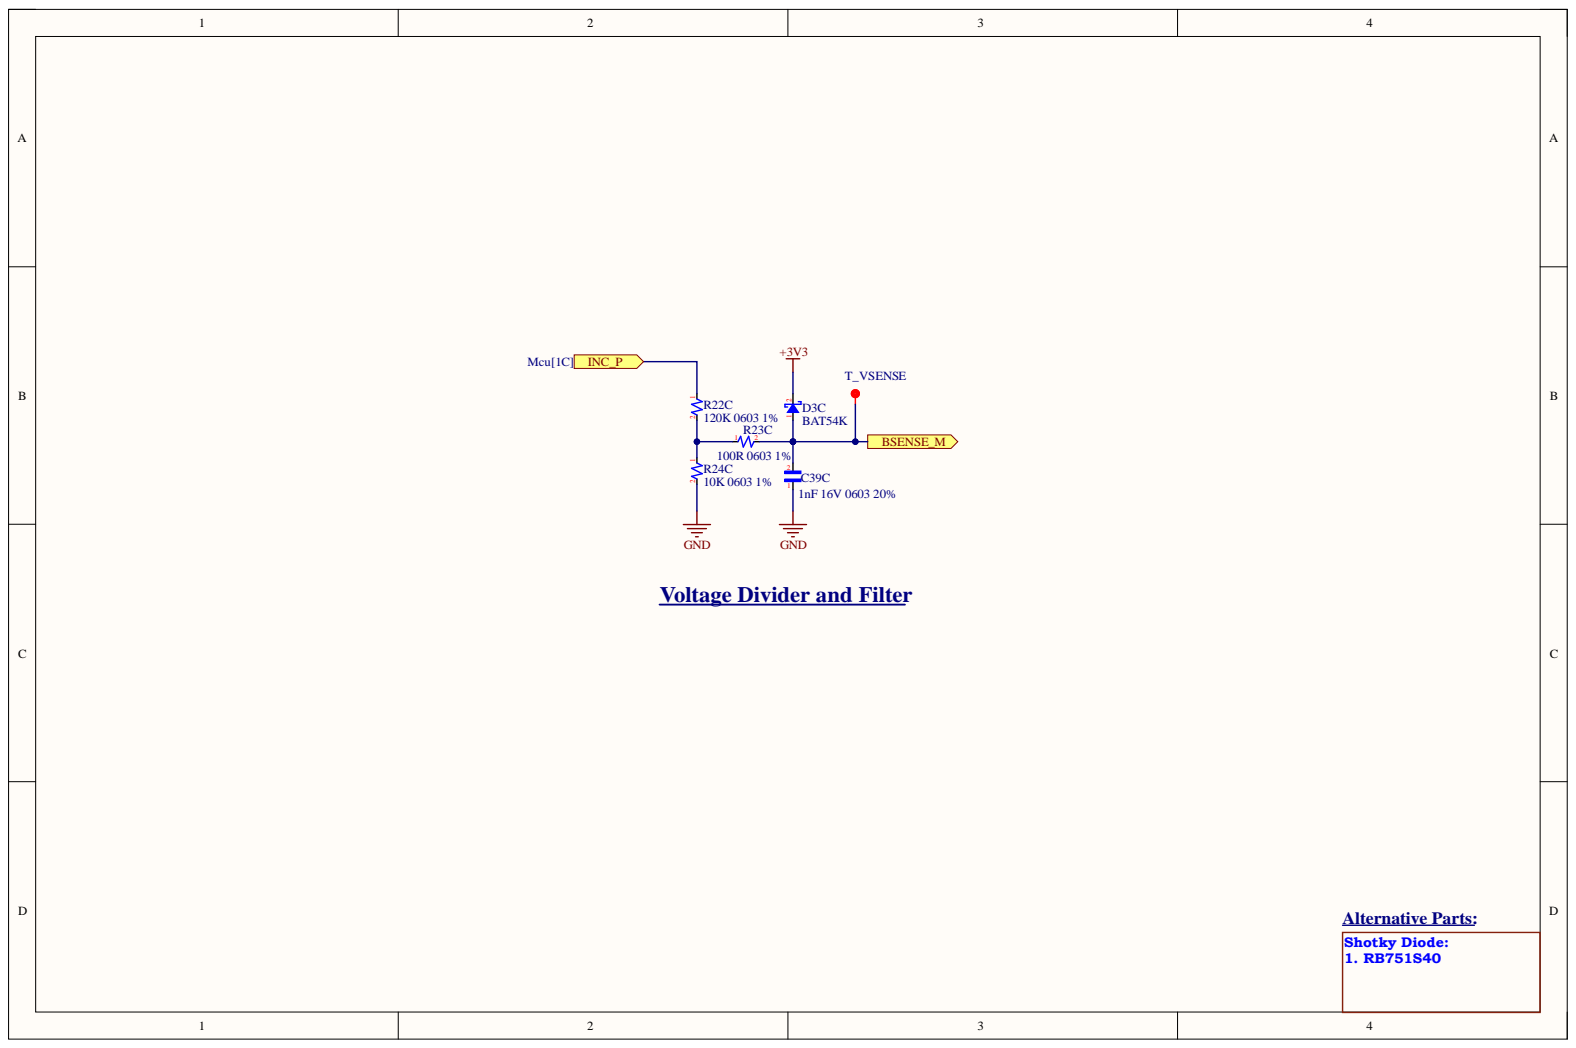
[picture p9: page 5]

Voltage Divider and Filter

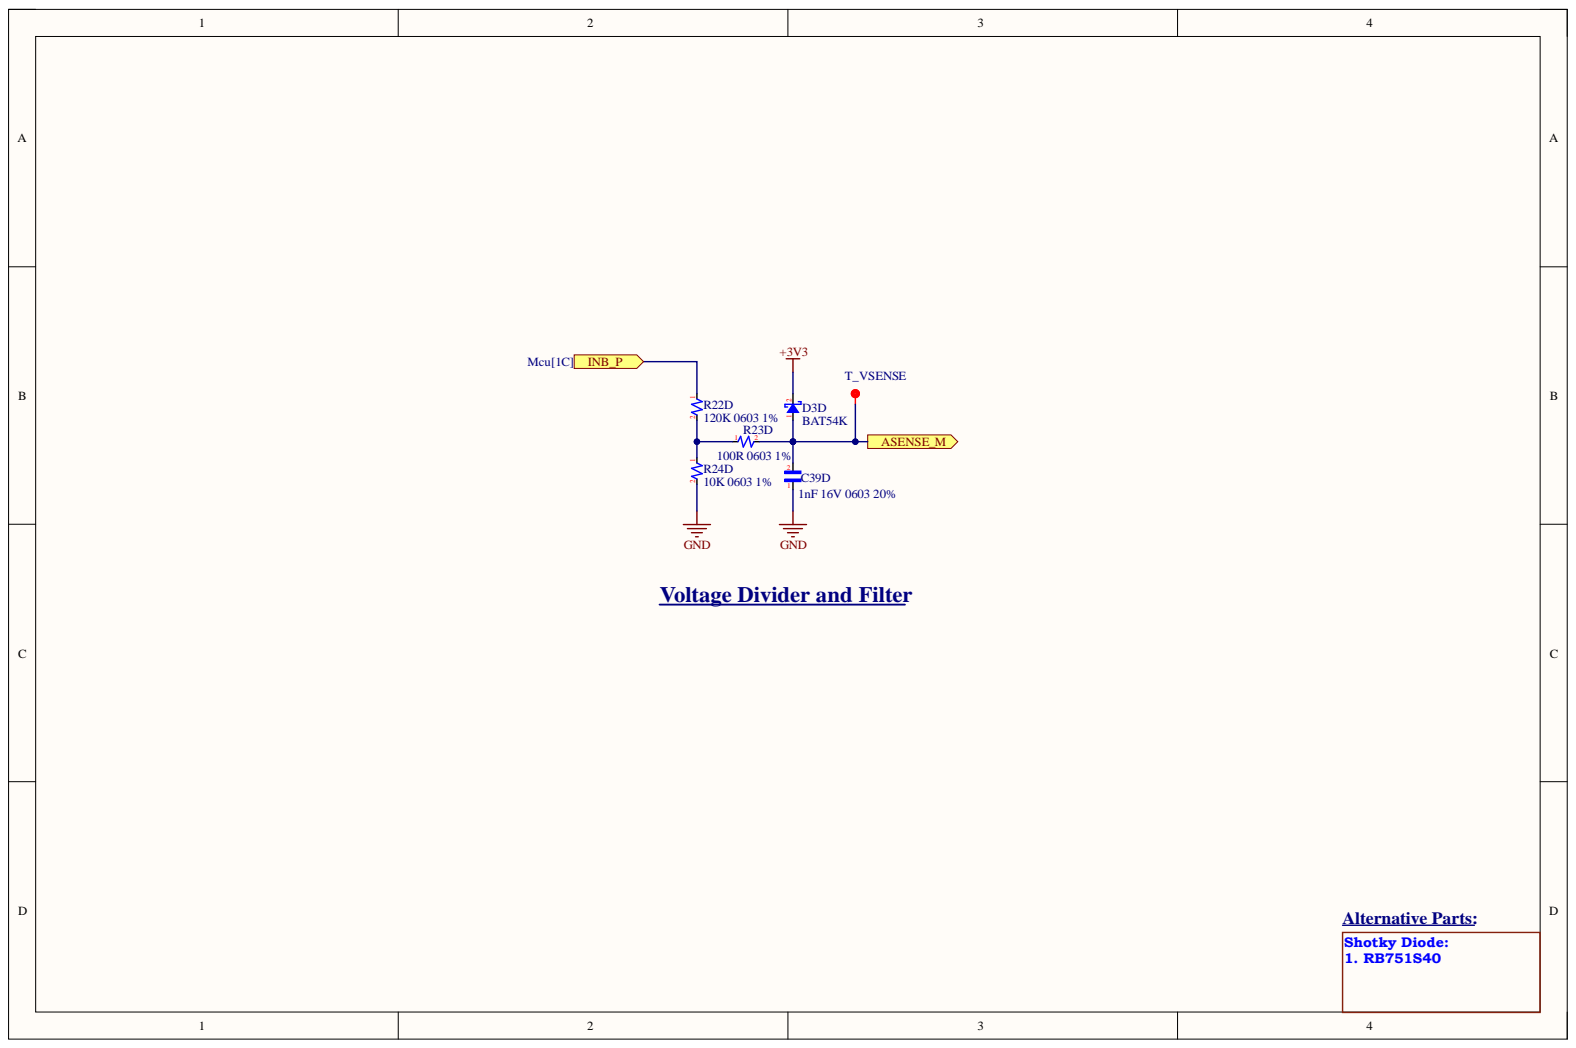
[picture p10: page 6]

Voltage Divider and Filter

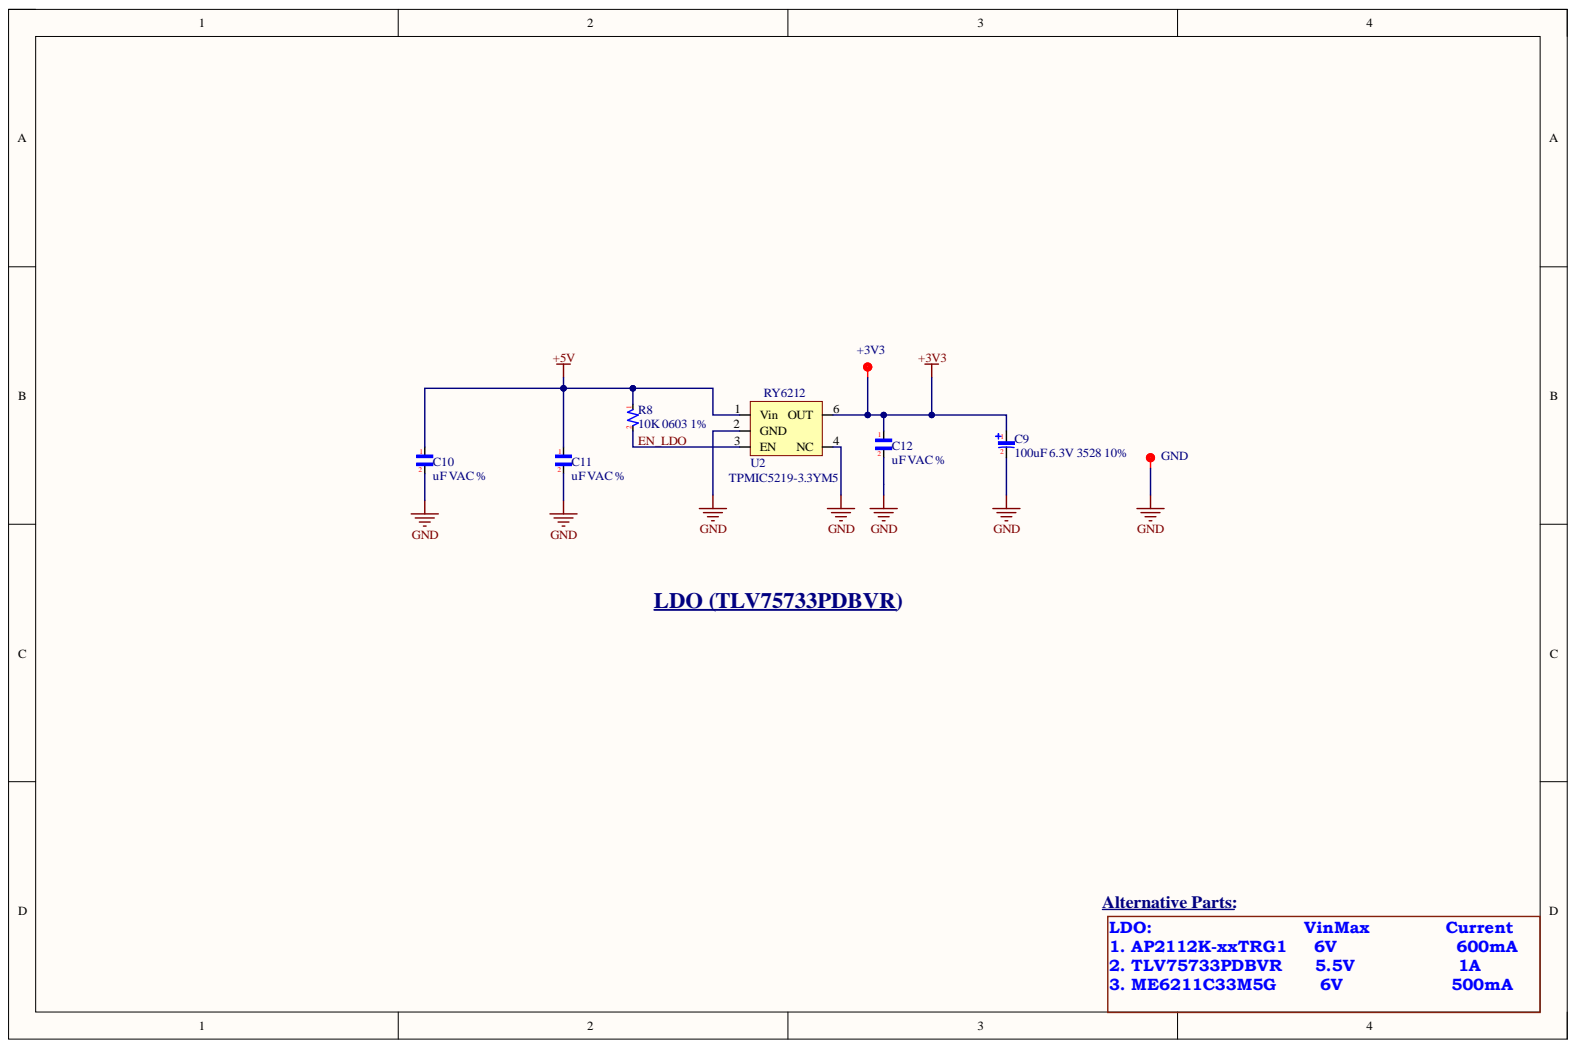
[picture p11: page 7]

R 8 1
10K 0603 1% 2 | | 4
EN_ LD O | 3

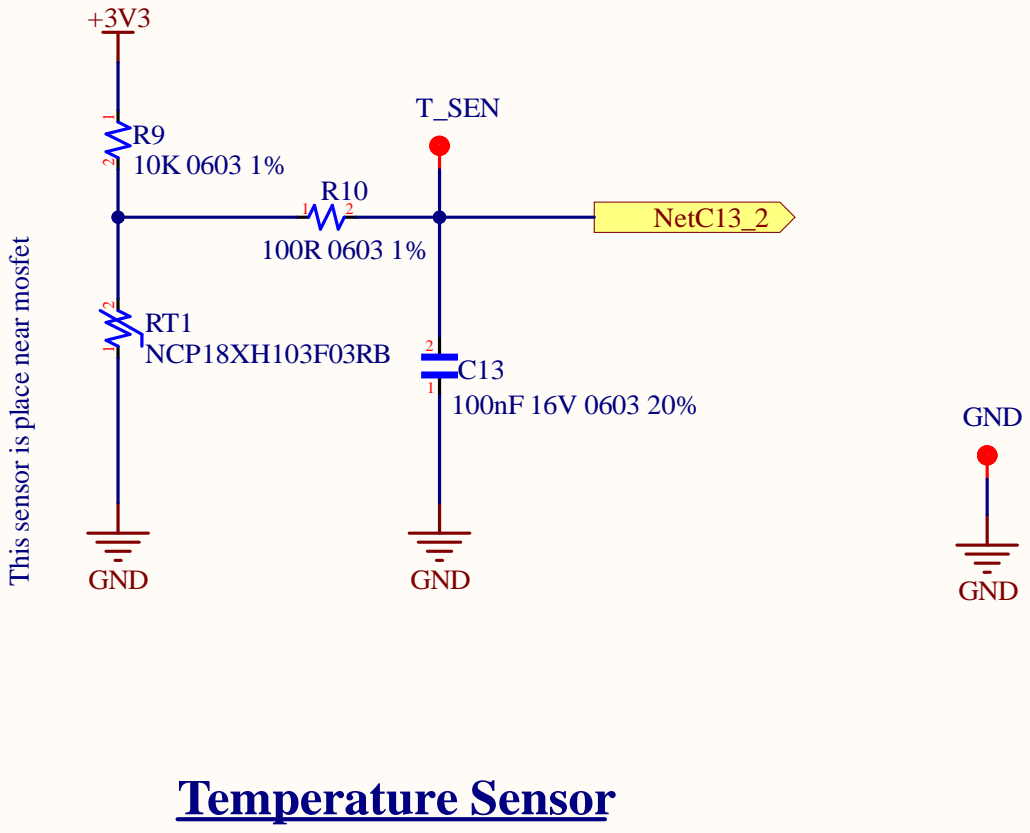
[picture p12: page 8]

Thissensor is place near mosfet
